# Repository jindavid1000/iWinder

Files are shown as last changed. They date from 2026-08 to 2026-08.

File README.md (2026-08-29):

<div align="center">

### 3D 打印智能绕线器 · 手机 APP 无线控制

ESP32 + 舵机丝杆排线 + 直流电机收线，把散装线材整齐绕到任何料盘上。

**不只绕耗材——电线、绳线、织带，通通能绕。**





</div>

---
QQ 交流群：1103884695

## ✨ 项目亮点

- 📱 **手机 APP 无线控制** — WiFi 连接，实时监控转速/长度/排线位置，不用守在机器旁边
- 🧵 **自适应排线** — 排线速度根据料盘实际转速自动同步，每圈移动一个线径，紧密排列无间隙
- 🎛️ **全程可调** — 线径、料盘尺寸、速度、排线范围全部 APP 里改，支持保存 10 组预设方案
- 🔧 **几乎兼容所有料盘** — 拓竹、eSUN、随便什么牌子，尺寸不合适随时调参数
- 💰 **成本低** — 全套约 ¥56+（不含打印件），手摇版最省
- 🔓 **部分开源** — APP 源码、固件外围源码、硬件与 3D 模型开放（非商业）；核心排线算法闭源，固件以二进制发布

## 🎯 能绕什么？

| 线材类型 | 说明 |
|---|---|
| 3D 打印耗材（PLA/PETG/TPU...） | 1.75mm / 2.85mm / 3mm，默认拓竹 1kg 料盘 |
| 电线 / 线束 | 绕到线盘上，排线整齐不乱 |
| 钓鱼线 / 细绳 | 换个料盘就能绕 |
| 织带 / 扁平带材 | 调整排线间距即可 |

> 只要料盘装得上去、参数调得好，什么都能绕。

---

## 📸 效果展示

### 整机外观

<div align="center">



</div>

### APP 界面

<div align="center">
<table>
<tr>
<td align="center"><b>设备连接</b></td>
<td align="center"><b>控制面板</b></td>
</tr>
<tr>
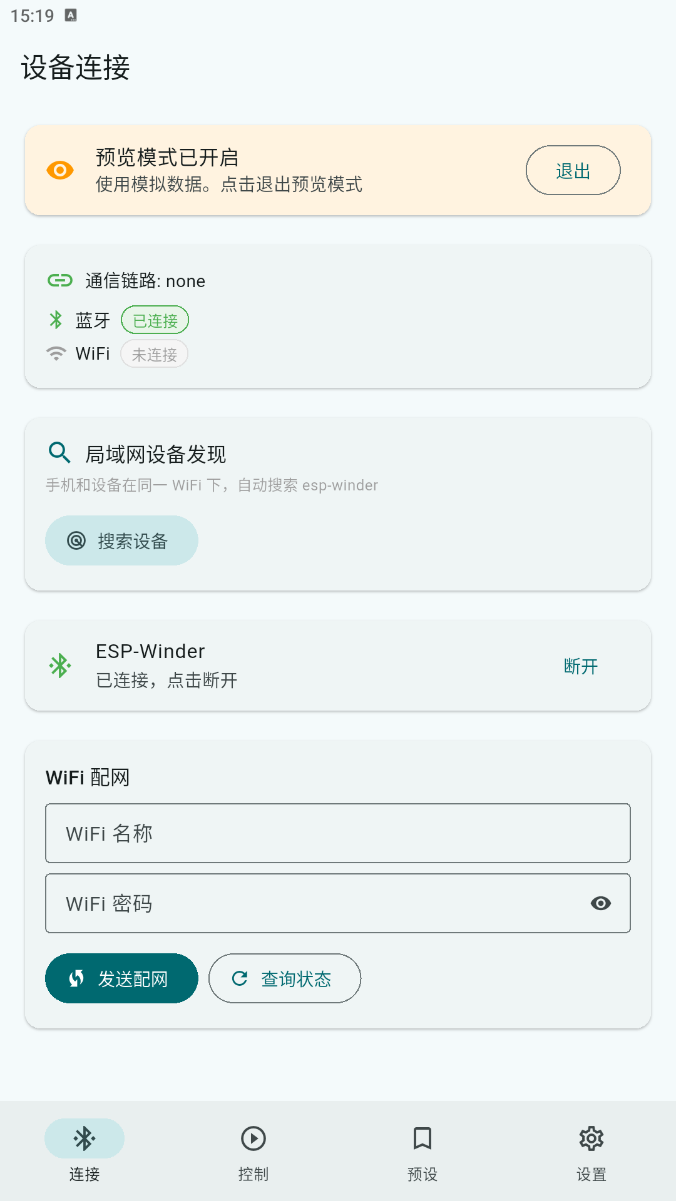
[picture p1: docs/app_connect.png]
<td align="center"><br><sub>WiFi 配网 / 局域网搜索 / 直连 IP</sub></td>
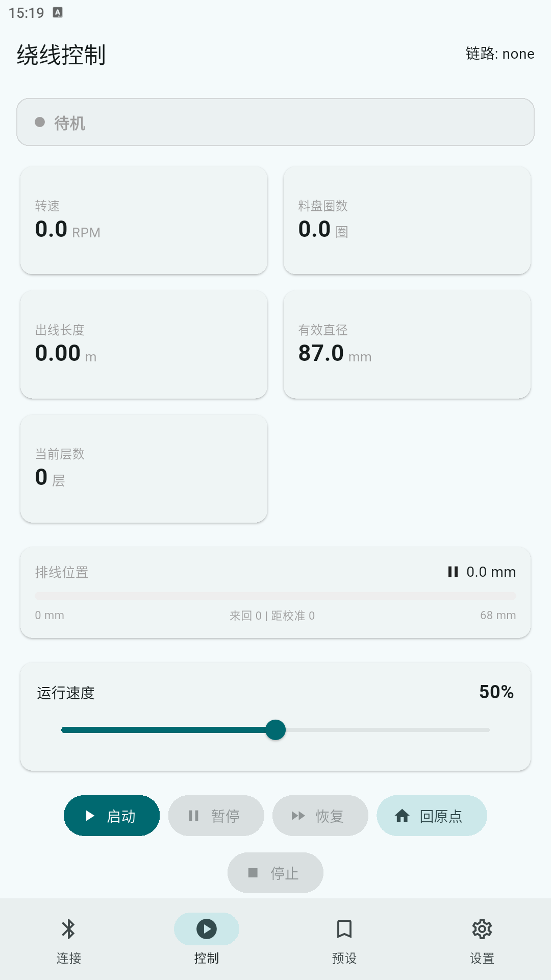
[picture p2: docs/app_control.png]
<td align="center"><br><sub>启停控制 / 实时调速 / 运行监控</sub></td>
</tr>
</table>
</div>

<div align="center">
<table>
<tr>
<td align="center"><b>参数预设</b></td>
<td align="center"><b>设置页面</b></td>
</tr>
<tr>
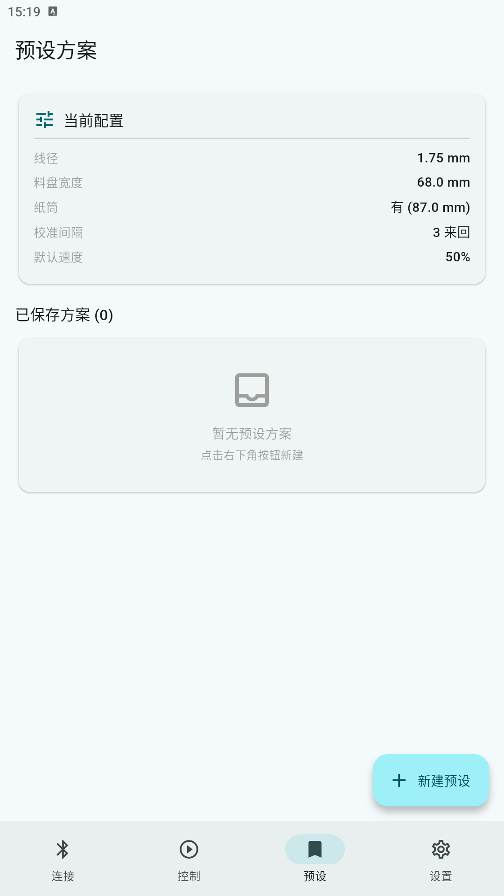
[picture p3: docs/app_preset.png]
<td align="center"><br><sub>料盘参数管理 / 一键切换方案</sub></td>
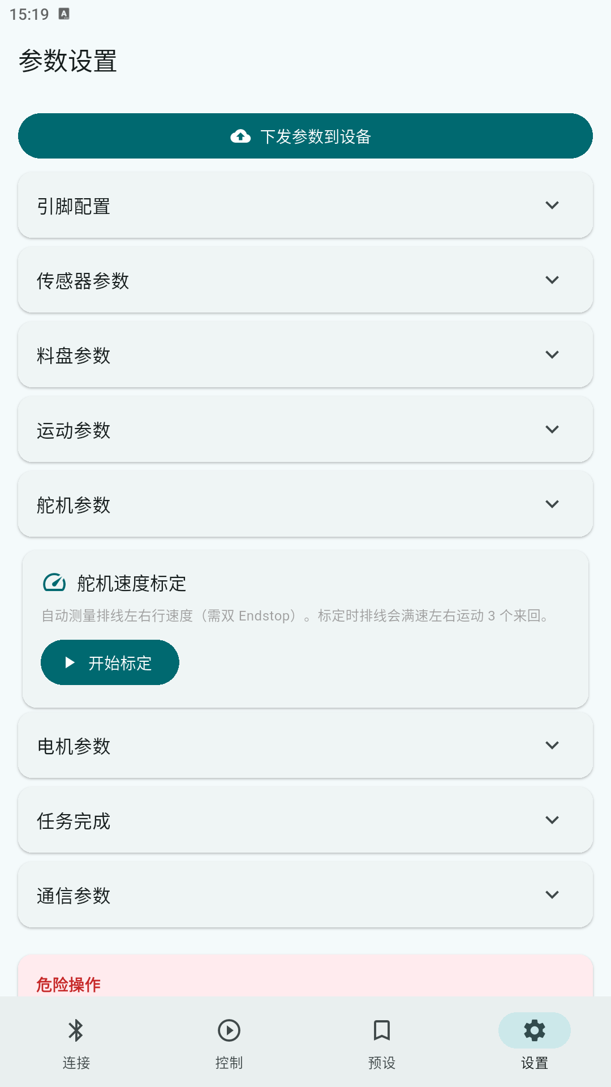
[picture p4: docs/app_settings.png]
<td align="center"><br><sub>引脚/传感器/舵机/电机全部可调</sub></td>
</tr>
</table>
</div>

### 运行演示

> 🎬 运行 GIF 待补充（绕线过程 + APP 实时数据）

---

## 🏗️ 组装

> 详细组装视频可参考原作者 [废改实验室](https://makerworld.com.cn/zh/models/2379707-san-liao-rao-xian-qi-shou-yao-dian-dong) 的教程（电机部分）。
> 图文安装说明见 [`docs/安装说明.pdf`](docs/安装说明.pdf)。

### 版本选择

本项目提供三个版本，核心排线机构相同，区别在收线驱动方式：

| 版本 | 成本（不含打印件） | 适合人群 | 特点 |
|---|---|---|---|
| **手摇/电钻** | ~¥56 | 预算有限 | 手摇或电钻驱动，最经济 |
| **单电机** | ~¥80 | 推荐首选 | 电机自动收线，解放双手 |
| **双电机** | ~¥98 | 追求扭矩 | 双电机驱动，更强力 |

> 详细 BOM 见 [`BOM/`](BOM/) 目录（含拼多多链接和价格）。

### 硬件清单

| 部件 | 规格 | 说明 |
|---|---|---|
| 主控板 | ESP32-DevKitC（普通版） | |
| 收线盘电机 | 直流减速电机 6V 40RPM | 单向收线（单/双电机版） |
| 电机驱动（二选一） | ① IRLB8721 MOS + 150Ω/10kΩ 电阻 + 1N5822（PWM 调速）② L298N 模块（开关，不调速） | ①不可用 IRF520（栅极需 10V）；②接线简单：ENA 插跳线、IN1=GPIO4、IN2=GND |
| 排线编码器（可选，强烈推荐） | AS5600 磁编码器模块 + Φ6 径向磁铁 | 直测丝杆，闭环位置精度 ±0.1mm 级 |
| 排线舵机 | MG946R 360° 连续旋转（首选）/ 鑫辉 18KG（备选） | 驱动丝杆排线 |
| 丝杆 | T8 四头丝杆 + 螺母（导程 22mm） | |
| 霍尔传感器 | KY-003（A3144）× 1 | 料盘计圈 |
| 磁铁 | N35 Φ6×2mm × 8 | 贴在料盘上配合霍尔 |
| 限位开关 | 摆杆式 Endstop × 2 | 左原点 + 右限位 |
| 轴承 | 608ZZ × 8 | |
| 电源 | 多路降压模块（3.3V/5V/12V） | 鹿小班 DCP3512 或等效 |

<details>
<summary>📌 舵机说明（点击展开）</summary>

- **首选：MG946R 360° 连续旋转舵机**（泰尔科技，约 ¥12.2）
  - 需额外打印「模型/配置/mg946 改双轴.3mf」改装件
  - 参考项目：[MG996R 双轴舵机适配器](https://makerworld.com.cn/zh/models/538013) by LaphaeL
- **备选：鑫辉 18KG 360° 连续旋转舵机**（约 ¥31）
  - 自带金属舵盘，无需改装件
  - 支持 7.4V，扭矩更大
- ⚠️ 两个都是 **360° 连续旋转舵机**，不是普通 180° 位置舵机

</details>

### 接线

**ESP32 信号线**

| ESP32 引脚 | 连接 |
|---|---|
| GPIO 4 | 电机驱动：MOS 方案接栅极（经 150Ω），L298N 方案接 IN1 |
| GPIO 5 | 舵机 PWM 信号线 |
| GPIO 14 | Endstop 左（绕线起始侧）信号 |
| GPIO 32 | Endstop 右（**原点侧**，上电寻原点时小车停靠的一侧）信号 |
| GPIO 27 | 霍尔传感器信号 |
| GPIO 21 | AS5600 编码器 SDA（可选） |
| GPIO 22 | AS5600 编码器 SCL（可选） |
| GPIO 2 | 板载 LED（状态指示，无需外接） |

**供电**

| 电源模块输出 | 连接 |
|---|---|
| 3.3V | ESP32 3V3 脚、霍尔传感器 VCC、Endstop 信号公共端、AS5600 VCC |
| 5V | 舵机 VCC |
| 12V | 电机供电：MOS 方案——电机正极，电机两端并联 1N5822 续流二极管（负极朝 12V 端），电机负极接 IRLB8721 漏极（D），源极（S）接 GND，栅极经 150Ω 接 GPIO4、10kΩ 下拉到 GND；L298N 方案——接模块 +12V 输入 |
| GND | 所有模块共地 |

> ⚠️ ESP32 的 GND 必须与电机/舵机电源的 GND **共地**，否则 PWM 信号不稳定。
> ⚠️ **电机 PWM 线（GPIO4）不要与舵机信号线（GPIO5）并排/捆扎走线**——PWM 开关噪声
> 会耦合进舵机信号，导致排线在"停止"状态下仍缓慢漂移。固件已将电机 PWM 提到 20kHz
> 缓解，但布线时仍应分开；更稳妥可在舵机信号线上加 RC 滤波（串 1kΩ + 对地 100nF）。
> ⚠️ **AS5600 磁铁装丝杆轴端**，轴向对准芯片中心、间隙 0.5~2mm、尽量同心——
> 磁铁偏心是这类编码器最大的误差源。装好后先跑 `test_encoder` 验证无漂移。
> ⚠️ **Endstop 安装**：以"刚刚触发"状态为基准（摆杆压过咔哒点再多 0.3~0.5mm 固定），
> 剩余超程作为寻原位停止冲量的缓冲。两个限位触发点之间的真实距离用 `test_encoder`
> 测出（小结行会打印），填入「限位间距」参数——限位绝对装在哪不重要，重复性才重要。
> 引脚全部可在 `esp32/include/config.h` 中修改，也可通过 APP 运行时调整。
> ⚠️ **限位左右别接反**：以功能区分——**右限位是原点侧**（上电后小车寻原点时向右顶到的那个），
> 左限位是绕线起始侧。接反的典型表现：上电寻原点显示「右原点已确认」，随后定位立刻报
> `sensor_error - 定位顶左限位且偏差>3mm`，且串口 `[POS]` 行末尾**同时**出现 `[左限位] [右限位]`。
> 修法：对调 GPIO 14 / GPIO 32 两根信号线，或在 APP 设置页把两个限位引脚值互换。
> 接好后可用 `pio run -e test_endstop -t upload` 分别按压两个摆杆验证左右一一对应。

### 3D 打印

`模型/` 目录下提供所有打印件。推荐使用 Bambu Studio 切片，**PETG**（所有模型均在 PETG 下测试通过），PLA 也可以。

---

## 🚀 使用指南

### 第一步：烧录固件

固件以编译好的二进制发布（核心算法不开源），最新版本在本仓库 [`firmware/`](firmware/) 目录
（[Releases](../../releases) 页面有历史版本）。

**网页烧录（推荐，无需装任何软件）**：

1. USB 连接 ESP32 到电脑
2. Chrome/Edge 打开 **[esptool.spacehuhn.com](https://esptool.spacehuhn.com/)** → Connect 选串口
3. 第一个槽地址改成 **0x0**，选 `iWinder_full.bin`（合并镜像），其余槽留空 → Flash
4. 完成 → 重新上电，ESP32 启动热点 **ESP-Winder**

详细步骤（含增量升级方法）见 [`firmware/README.md`](firmware/README.md)。

**命令行烧录**（合并镜像一步完成）：

```bash
pip install esptool
esptool.py --chip esp32 --port 串口号 write_flash 0x0 iWinder_full.bin
```

烧录完成后设备自动启动热点 **ESP-Winder**（串口 115200 可看启动日志）。

> 💡 可单独测试硬件模块：`pio run -e test_motor -t upload`（可选：`test_led`、`test_servo`、`test_hall`、`test_endstop`、`test_encoder`、`test_wifi`）
>
> `test_encoder` 会驱动排线满速来回扫描（限位自动换向），打印编码器角度/圈数/位置/速度、
> 磁场质量诊断和匀速偏心检测，并在每趟小结限位间圈数 × 导程（⚠️ 含停稳回弹约 5mm，
> 精确限位间距以定位日志的右锚定坐标 − 左触发坐标为准）。

### 第二步：安装 APP

**最简方式（推荐）**：无需安装任何东西——烧录固件后，手机/电脑浏览器直接访问设备：

- 热点模式：连上 WiFi **ESP-Winder** 后打开 `http://192.168.4.1`
- 家庭 WiFi 模式：iOS/macOS 浏览器直接打开 `http://iwinder.local`（mDNS 自动解析）；
  其他设备可从串口日志或 App「搜索设备」获取 IP 后访问

Web 界面支持控制（启停/调速/手动模式）、实时状态、参数修改和舵机标定，iOS/安卓/电脑通用。
只要设备连入了局域网（家庭 WiFi）或开着热点（ESP-Winder），同一网络内的任何浏览器
都可以访问，无需安装、无需账号；可多端同时在线，与安卓 App 互不干扰。

> ⚠️ 家庭 WiFi 模式要求访问设备与 ESP32 连**同一个路由器**，且路由器关闭了
> 「AP 隔离 / 客户端隔离 / 访客网络隔离」——开着隔离的表现是能解析出
> `iwinder.local` 但页面打不开。部分路由器对 IoT 设备默认隔离，需要在管理界面放行。
>
> 💡 设备端负载：Web/APP 在线时 CPU 占用 <15%，控制循环为闭环设计（编码器实测位置 +
> 硬件 PWM），偶发的网络处理延迟（毫秒级）不影响绕线精度，多端同时连接也无需担心。

也可以使用功能更完整的安卓 APP：

从本仓库 [`firmware/`](firmware/) 目录下载最新 `app-release.apk`，传到手机安装
（[Releases](../../releases) 有历史版本）。

<details>
<summary>或自行编译（需要 Flutter 环境）</summary>

```bash
cd app
flutter pub get
flutter build apk --release
# 产物：build/app/outputs/flutter-apk/app-release.apk
```

</details>

### 第三步：连接设备

ESP32 上电后会启动 **WiFi 热点（ESP-Winder）**。

1. 手机 WiFi 设置里连接热点 **ESP-Winder**
2. 打开 APP → IP 填 `192.168.4.1`，端口 `8080` → 连接
3. 在「WiFi 配网」输入家庭 WiFi 密码 → 发送配网
4. 手机切回家庭 WiFi，以后用「搜索设备」自动发现连接

### 第四步：开始绕线

1. **选驱动模式**：设置页「驱动模式」→ 电动（电机驱动）或 手动（手摇驱动，电机不输出）。
   用 L298N 驱动板的话把「电机驱动电路」切到 L298N——此模式无调速，电动模式启动即全速
2. **选预设**：默认拓竹 1kg，可自定义线径/料盘尺寸
3. **标定**（设置页）：
   - 装了 AS5600：切「AS5600 编码器闭环」（齿比填 1.0），点「舵机速度标定」——
     自动测量满速/步进速度、编码器每圈位移并写入 NVS
   - 未装编码器：用默认「舵机开环估算」，必须先跑「舵机速度标定」才能启动
4. **启动**：电动模式拖速度滑块调速启动；手动模式直接启动后手摇，排线自动跟随转速
5. **运行监控**：APP 实时显示转速、圈数、长度、排线位置
6. **停止**：点「停止」，排线自动回原点归位

**手动模式行为**：手摇越快排线越快，停手约 1 秒排线暂停；停转约 2 秒（且来回数达标）
自动触发一次限位校准并回到原位置继续。电动模式带缠料保护（电机运转但料盘停转 4 秒
自动**暂停**并提示，清理后点「恢复」继续绕线，无需重新定位）。

---

## ⚙️ 参数调校

首次使用在 APP 设置页面配置/标定：

| 参数 | 说明 |
|---|---|
| 驱动模式 | 电动（电机）/ 手动（手摇），行为差异见上 |
| 电机驱动电路 | MOS 管调速（PWM，支持软启动/调速滑块）/ L298N 开关（ENA 插跳线全速，只能启停不能调速，方向由接线决定） |
| 位置反馈 | 舵机开环估算 / AS5600 编码器闭环（装编码器后强烈建议开启；绕线中为连续旋转速度自适应控制，平滑跟随） |
| 排线速度标定 | 自动测量满速 3 个来回 + 步进速度 1 个来回；编码器模式下还会标定每圈位移 |
| 限位间距 | 左右限位**触发点**之间的真实距离（默认 62mm）。⚠️ 用 `test_encoder` 测量时注意「右停稳→左触发」含柔性回弹（偏大约 5mm），最准的方法是：绕线/定位日志中右锚定坐标 − 左触发坐标 |
| 霍尔去抖 | 默认 25000us（滤除电机 PWM 耦合噪声），真实转速超 300RPM 才需调小 |
| 料盘参数 | 外径、宽度（拓竹料盘宽 60mm，默认已填）、芯轴直径（有/无纸筒可切换）——只影响长度/层数计算 |
| 绕线范围 | **右基准模型**：右终止位置（默认 62mm，由机器安装决定）+ 料盘宽度 → 左起始自动推导（= 右终止 − 宽度）。换盘只改宽度一个数字；料盘左右都不固定的特殊安装可勾「左起始手动指定」。绕线宽度 = 右终止 − 左起始，界面实时校验与料盘宽度的一致性 |
| 校准间隔 | 电动: 每几个来回校准一次；手动: 停转触发校准前至少需要的来回数 |
| 缠料保护 | 电动模式电机运转但料盘 0 转速持续 4 秒自动**暂停**（保留进度），清理后点「恢复」继续 |

所有参数支持保存为预设方案（最多 10 组），一键切换。ESP32 断电后参数保存在 NVS 中不会丢失。
⚠️ 固件升级若改动 DeviceConfig 结构体，首次启动会重置参数（WiFi 凭据保留），需重新配置下发。

---

## 📁 项目结构

```
├── app/            # Flutter 手机 APP（Android）源码
├── esp32/          # ESP32 固件外围源码（核心算法闭源，仅供参考）
├── firmware/       # 编译好的固件二进制与 APP 安装包（含烧录说明）
├── 模型/           # 3D 打印模型文件（.3mf，源文件为 Fusion 360 格式）
├── BOM/            # 硬件采购清单（三个版本）
└── docs/           # 安装说明等文档
```

---

## 🙏 鸣谢

- [废改实验室](https://makerworld.com.cn/zh/models/2379707-san-liao-rao-xian-qi-shou-yao-dian-dong) — 原始散料绕线器设计
- [LaphaeL](https://makerworld.com.cn/zh/models/538013) — MG996R 双轴舵机适配器

## 可选配件

- [耗材旋转支架](https://makerworld.com.cn/zh/models/1705115-hao-cai-xuan-zhuan-zhi-jia) — 放散料用，省料

---

## 🔑 申请授权

固件内置设备授权：**许可证免费申请，一人一机**。

**方式一：一键申请（推荐，全自动）**

设备连上 WiFi 后，在 Web 界面或 APP 的「授权」页填个昵称，点**「一键申请」**
即可自动获取并填入许可证（自动批准），点**激活**就能用了。也可以到
[授权网站](https://tt.jyking.dpdns.org:1000/) 网页申请：填设备 ID 提交，
把返回的许可证粘贴到设备「授权」页激活。

**方式二：QQ 群**

加入 QQ 群 **1103884695** 找作者，发设备 ID（授权页可查）即可。

> 未授权时可以正常连接、调参、回原点、标定，只是无法启动绕线任务。
> 许可证默认有效期一年，到期在原页面重新申请即可（免费，自动批准）。
> 商业授权（整机/套件销售、衍生产品）通过 QQ 群联系。

---

## License

本项目采用分层许可（详见 [LICENSE](LICENSE)）：

| 内容 | 许可 |
|---|---|
| 固件二进制 | 专有许可，免费激活使用，禁止逆向与商用 |
| APP / 固件外围源码 | PolyForm Noncommercial 1.0.0 |
| 3D 模型 / 硬件设计 / 文档 | CC BY-NC 4.0 |

3D 打印结构件为经原作者授权的二次创作设计，原作者不允许商用，本项目已获原作者许可并合作开发。

---

<div align="center">

制作不易，如果这个项目对你有帮助，欢迎 ⭐ Star 支持一下（当然如果愿意助力我买个 fusion 的话我也是不介意的😄）！
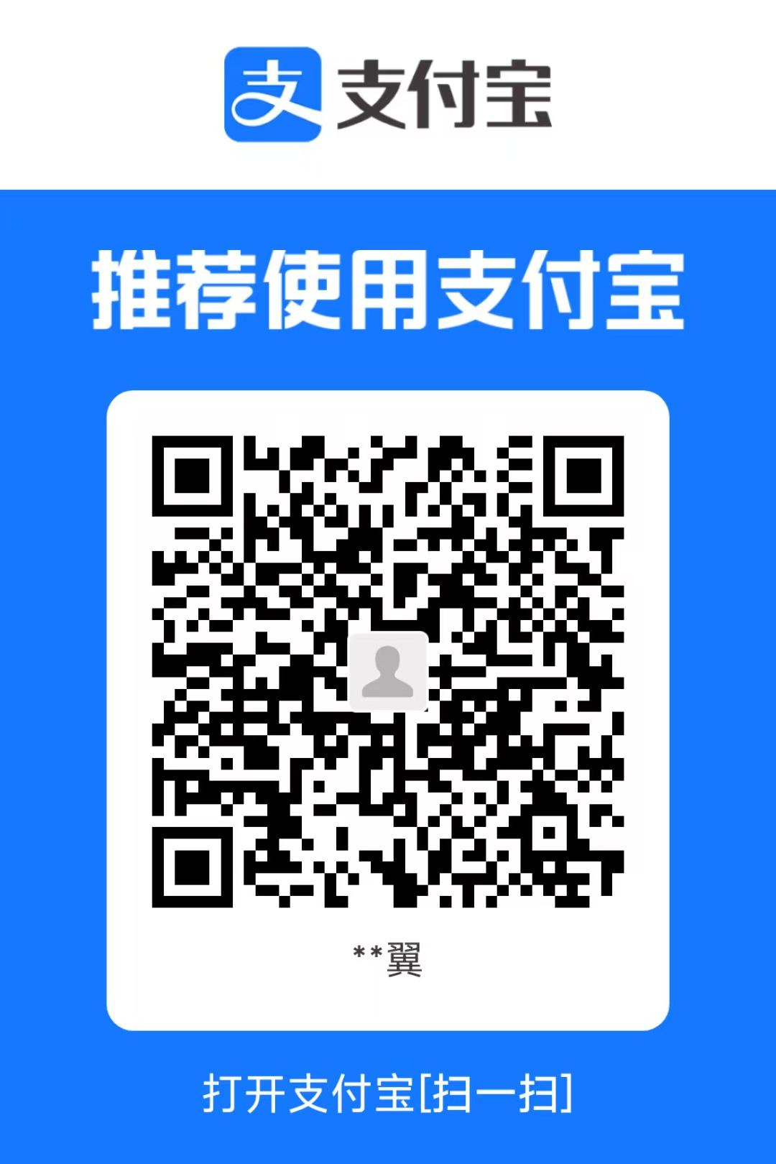
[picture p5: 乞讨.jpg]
截图


</div>

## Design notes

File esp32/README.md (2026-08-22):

# esp32/（固件外围源码，仅供参考）

本目录只包含固件的**外围部分**：通信、Web 界面、参数存储、传感器/电机/
舵机驱动等，供学习与二次开发参考。

**核心算法（自适应排线同步、绕线控制状态机、舵机标定）与设备授权模块不开源**，
仅以编译好的固件形式在 [Releases](../../releases) 发布。

因此本目录**无法独立编译成可用固件**。如需使用固件，请直接下载 Releases 中的
`.bin` 烧录；如需商业授权或算法合作，见项目 README。

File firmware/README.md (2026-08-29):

# 最新固件与 APP（v0.2.10）

| 文件 | 用途 |
|---|---|
| `iWinder_full.bin` | **推荐**。完整镜像（bootloader+分区表+固件），一条命令烧录 |
| `firmware.bin` | 仅应用固件，刷过旧版的设备更新用（`write_flash 0x10000`） |
| `app-release.apk` | 安卓 APP |

完整镜像烧录：

```bash
pip install esptool
esptool.py --chip esp32 --port 串口号 write_flash 0x0 iWinder_full.bin
```

> 这里只保留最新版本；历史版本见 [Releases](../releases)。
> 已联网设备可直接在 Web 界面「授权」页或 APP 在线升级（OTA），无需连电脑。

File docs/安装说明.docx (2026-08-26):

安装说明

一、零件展示

图示

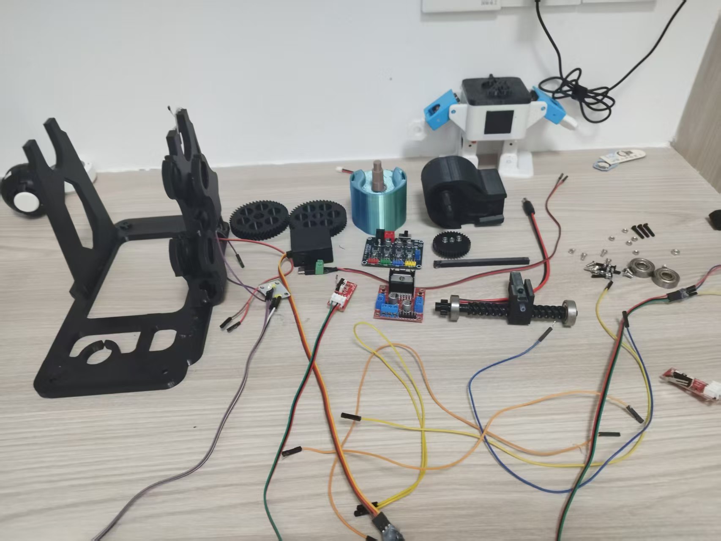
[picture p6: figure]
微信图片_20260826160315_27_6

二、丝杆和滑块安装

所需零件

特氟龙管一小节，丝杆、丝杆固定、螺母、从动小齿轮、as5600磁铁放置（打印件的名字），608zz轴承两个，m3*6螺母3个（滑块上)，m3*18螺丝一个，m2*18螺丝两个，as5600附赠的4*2直径充磁磁铁，，，，，（适量胶水）

操作说明

滑块：把特氟龙管插进去，然后用m3*6螺丝上紧，把整个滑块放进丝杆里，

丝杆：把两个轴承放到两端，然后用丝杆固定放在丝杆右边（伸出来轴短一点的那一边），用m3*18螺丝上紧（可能要打胶），左端按照顺序装配：先放从动小齿轮，再在上面放as5600磁铁放置，把孔位对齐，用m2*18螺丝上紧（上到底），然后把磁铁卡到as5600磁铁放置的正中心（可以让磁铁先吸到一块平的铁板上，然后用力的按下去）

图示

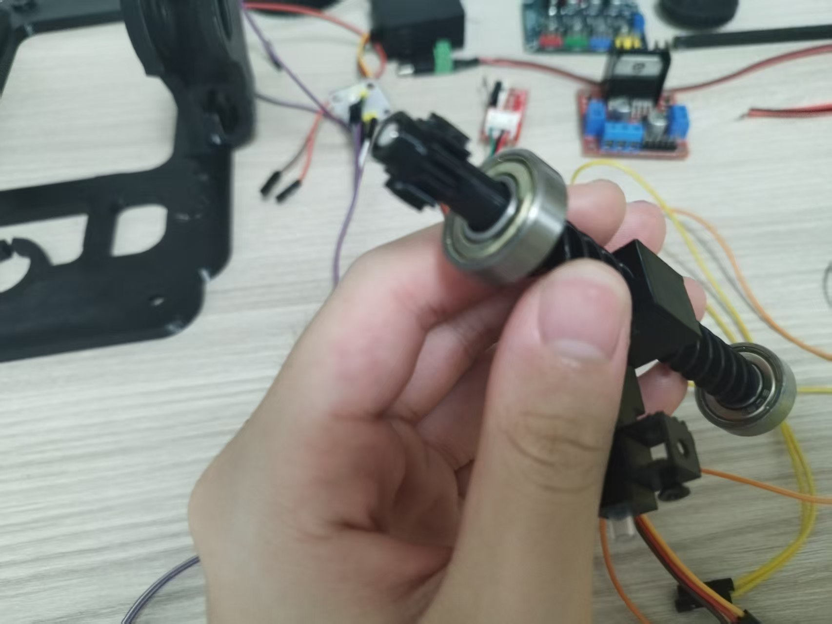
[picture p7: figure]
微信图片_20260826160314_25_6
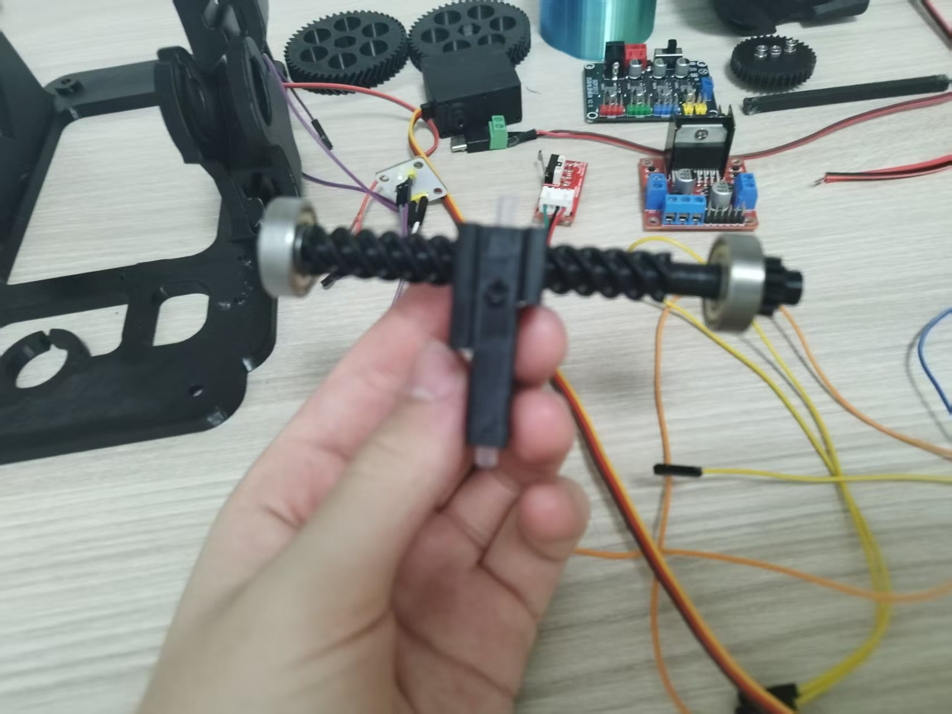
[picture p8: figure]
微信图片_20260826160314_26_6
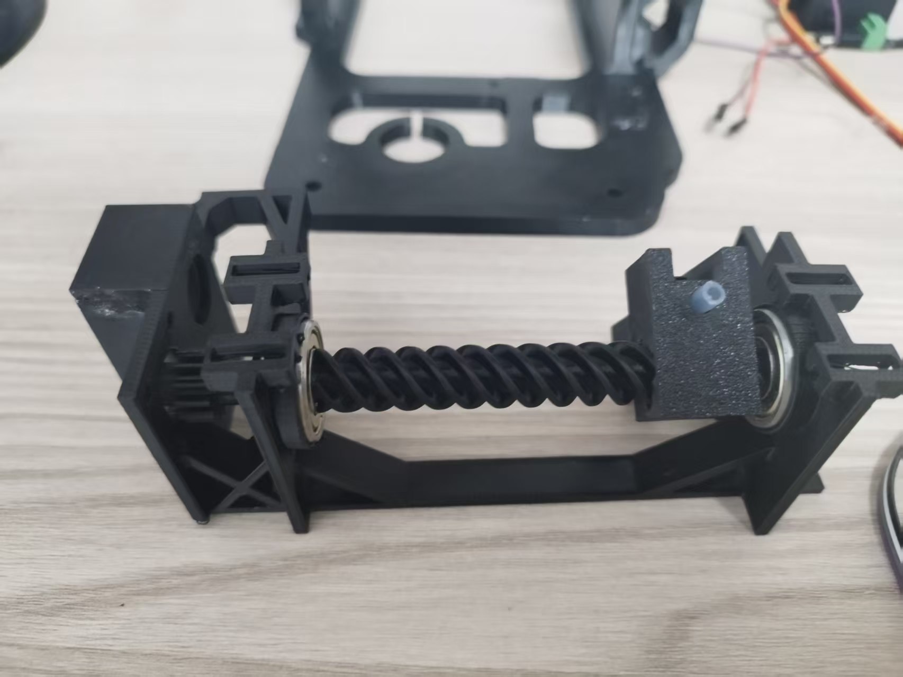
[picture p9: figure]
微信图片_20260826160311_22_6
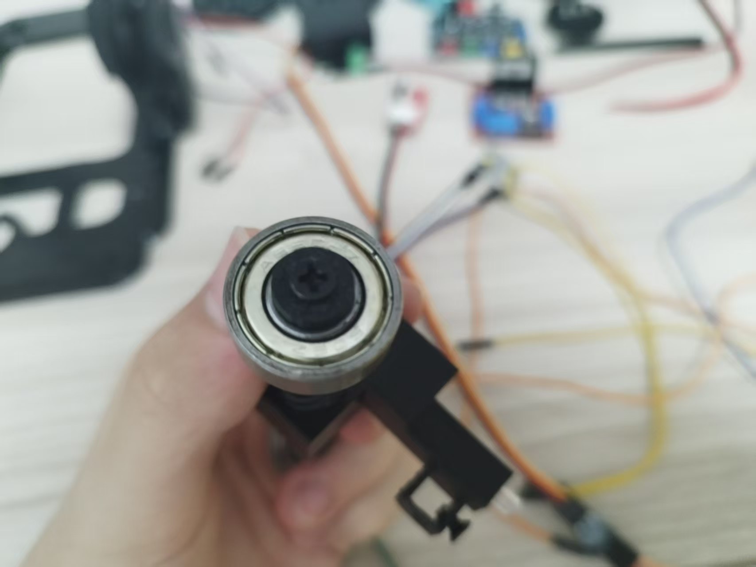
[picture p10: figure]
微信图片_20260826160312_23_6

三、舵机、舵盘和大齿轮安装

所需零件

金属的25T舵盘，舵机（用mg946r的话需要改），m3*10螺丝3个（没试过怎样，我看着应该是9mm的最完美，用12mm的话也可以，但是需自备螺母），主动大齿轮（打印件名字）

操作说明

把舵盘和大齿轮连接，中间一个连接舵机轴的螺丝先别上太紧，然后先把舵盘放进去，对准孔位，把舵机插进来，上紧螺丝

图示

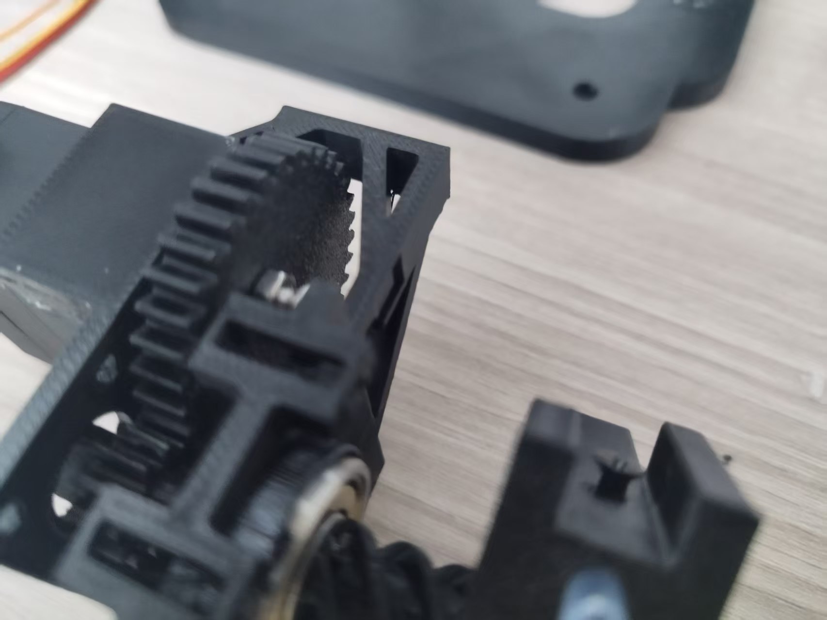
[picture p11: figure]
微信图片_20260826160308_19_6
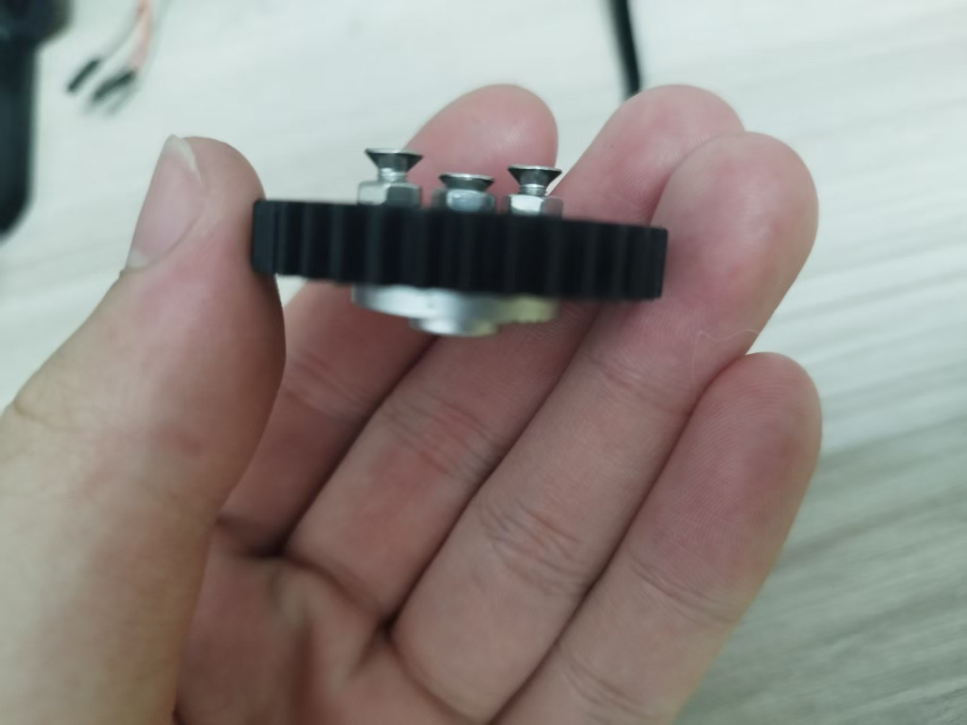
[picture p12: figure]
微信图片_20260826160310_21_6

四、固定杆安装

所需零件

平行于丝杆的定位小杆（打印件名字，好奇葩）

操作说明

对准孔位，用热熔胶固定即可

图示

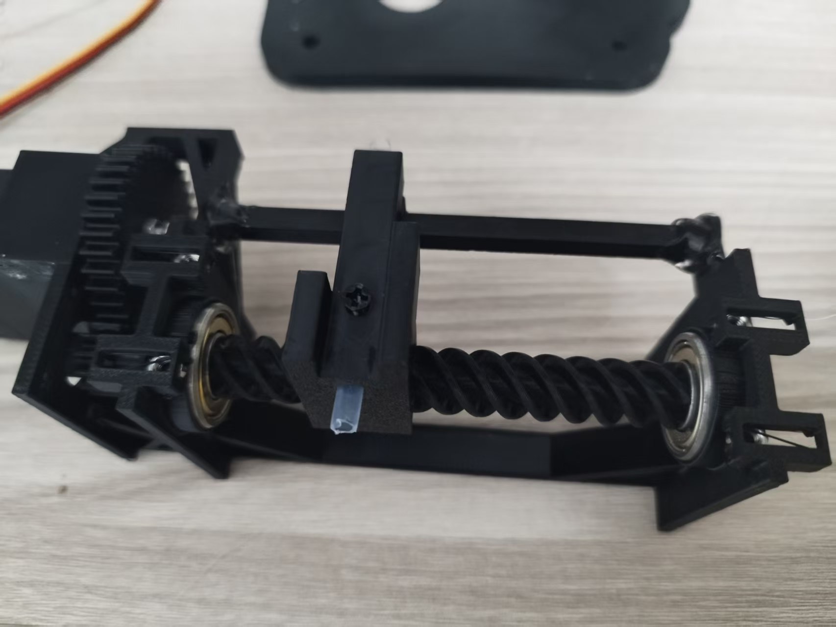
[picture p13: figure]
微信图片_20260826160306_16_6

五、endstop 安装

所需零件

两个endstop，4个m3螺母，4个m3*8螺丝，

操作说明

把核心框架翻到反面，用在四个框中塞入4个螺母，推到底，把endstop放到上面，用螺丝固定，可稍微调整

图示

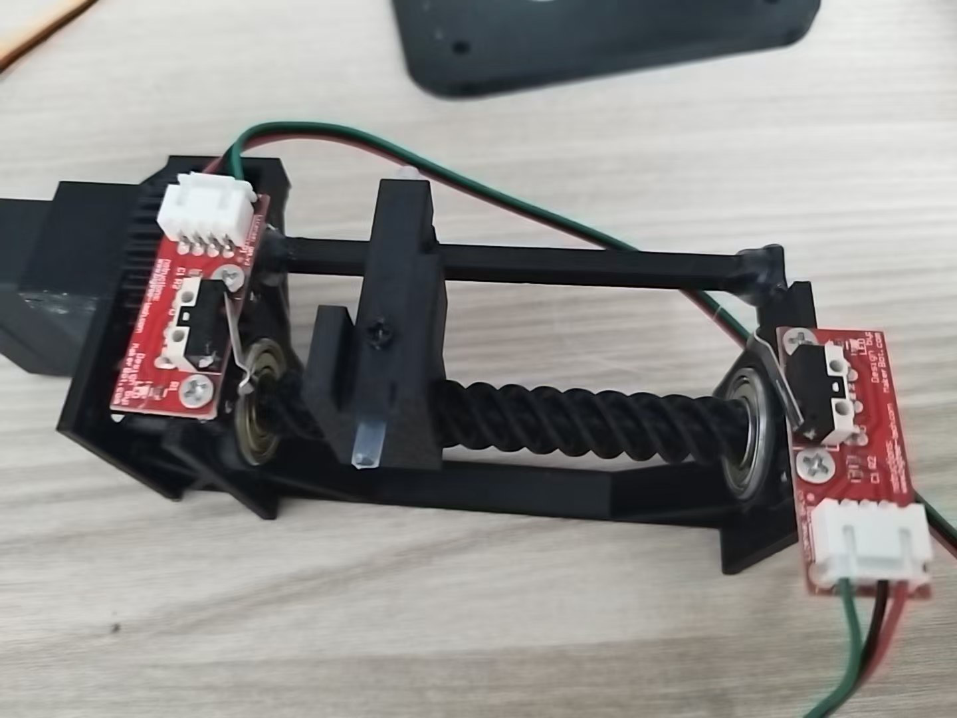
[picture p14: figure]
微信图片_20260826160305_15_6

六、as5600 编码器安装

所需零件

as5600编码器，m3*8螺丝4个，m3螺母4个

操作说明

把螺丝放进as5600的孔位，然后稍微上紧螺母，让螺丝的头和螺母齐平，对准核心框架侧边的孔位，上紧（注意方向，as5600一定要保证3个针脚的朝上）

图示

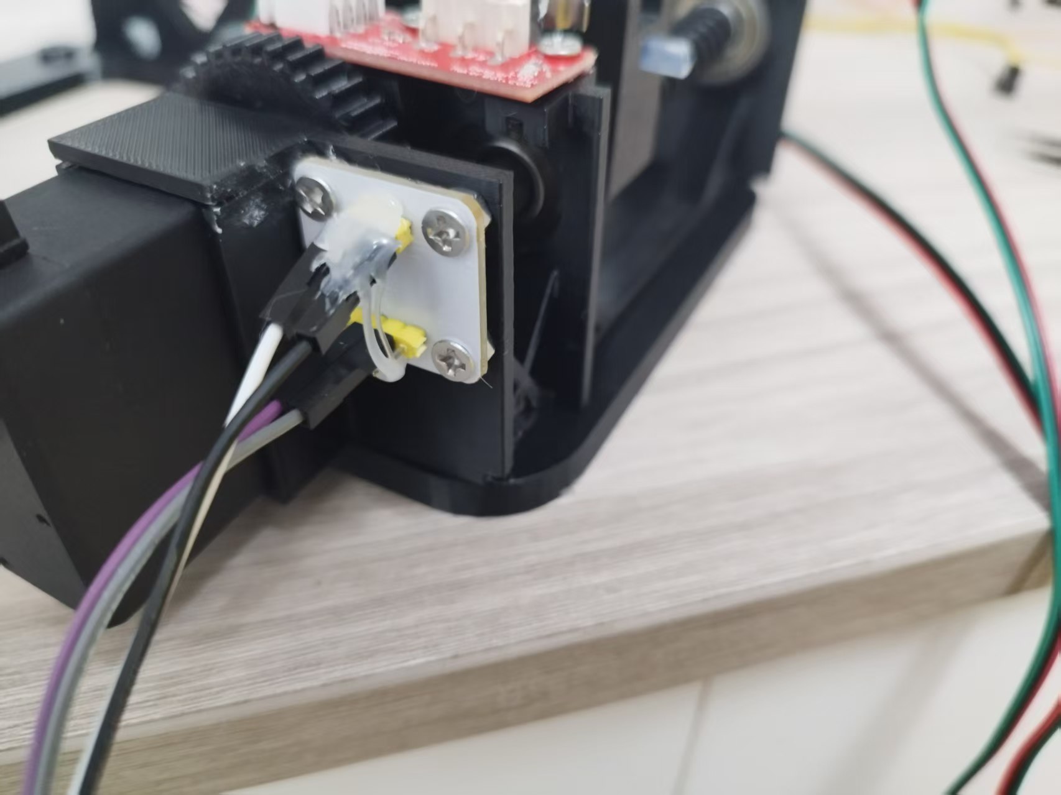
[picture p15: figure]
微信图片_20260826160302_12_6

七、总装配

所需零件

m3*8螺丝6个，m3螺母6个，（电源的孔位是给鹿小班开的，如果买的是bom上的直接用热熔胶，那么螺丝螺母只要3个）ky003霍尔模块，mos管（需要电阻和二极管，可以搞一个小面包板装好）或l298n

操作说明

把前面做好的核心模块固定到主体上（左边放螺母的地方需要用电烙铁加热螺母放进去，），然后用热熔胶粘上霍尔，调整好位置，电源如果用的是bom里的就也粘在侧面就行，其它有螺丝孔的就压入螺母，放上模块，用螺丝上紧

图示

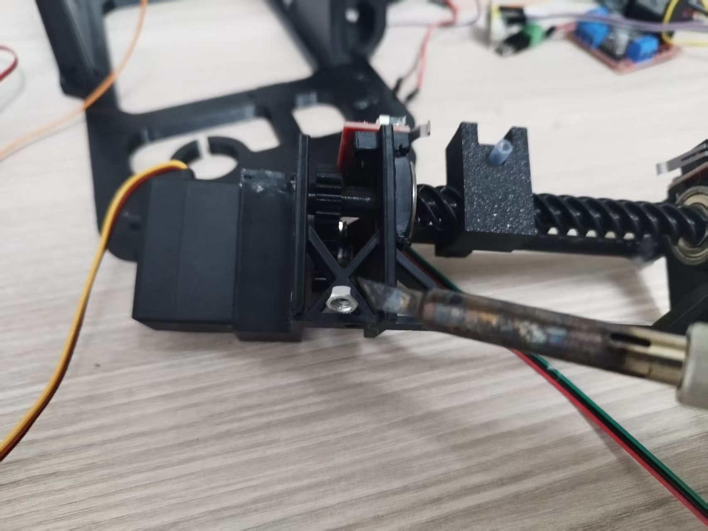
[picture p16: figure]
微信图片_20260826160304_14_6

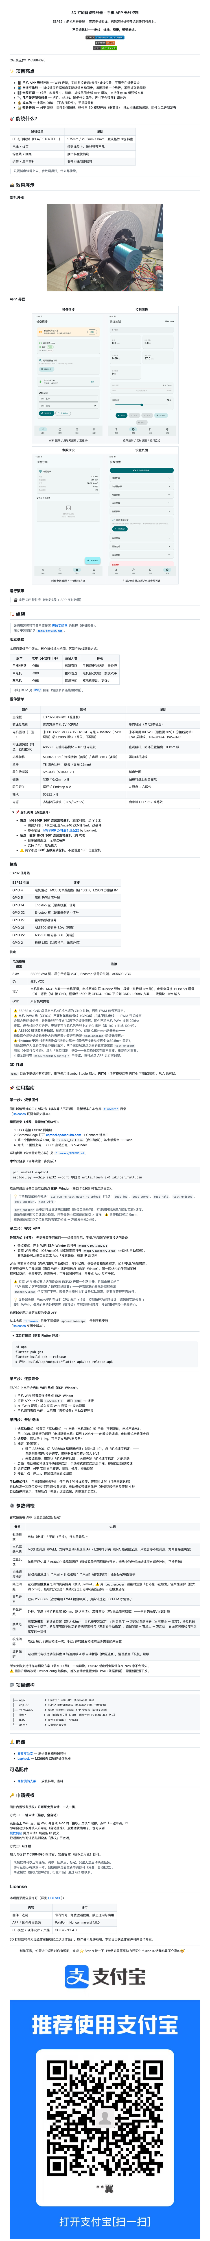
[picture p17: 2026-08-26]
readme.png

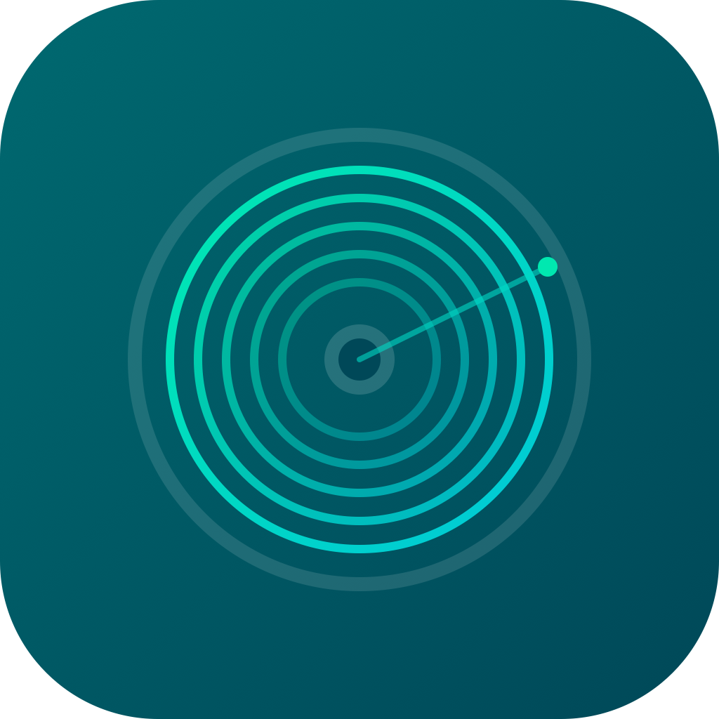
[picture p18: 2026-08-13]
app/assets/ic_launcher.svg.png

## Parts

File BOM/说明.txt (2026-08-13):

所有零件都可以在拼多多购买（价格全部为券前价），用什么版本看自己的需要，核心部分都是一样的，不一样的只有驱动部分，比较推荐手摇版，经济实惠，可以使用电钻等工具加速，单电机就比较省心（需注意接线），电机直接挂在上面，可以解放一只收，双电机具有单电机的有点，并且扭矩更强，但是接线更麻烦，需要注意，如果想做电机但是手残可以到废改3d散料盘料耗材的咸鱼看看，他是原作者

【舵机选择】
首选 MG946R（360°连续旋转版，泰尔科技，约12.2元），需要额外打印「模型/配置/mg946 改双轴.3mf」这个改装件把舵机的外壳改的适配这个项目（如使用此舵机，需另备金属舵盘或者在 makerworld 上找一个 25t 的花键舵盘，推荐 6v，不能更高）。
备选鑫辉科技 18KG 360°连续旋转舵机（买自带金属舵盘的版本或者在 makerworld 上找一个 25t 的花键舵盘，无需改装件，约31元（金属舵盘价）推荐 7.4v）。
注意：两个舵机都是 360° 连续旋转舵机，不是普通的 180° 位置舵机。

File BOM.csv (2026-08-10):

序号 | 名称 | 规格/型号 | 数量 | 单价(元) | 小计(元) | 备注
1 | DC电源插座 | 5.5×2.1圆形母座 配防水帽 5个装 | 1 | 3.24 | 3.24 | 达拉然电子配件
2 | 直流减速电机 | DC6V D型出轴 50转/分 大扭矩 | 1 | 18 | 18
3 | PWM电机调速器 | 1803BK 1.8-12V 2A 带开关 | 1 | 3.08 | 3.08 | 尚芯宇电子科技
5 | 608ZZ轴承 | ABEC-7 10个装 | 1 | 3.1 | 3.1 | AM轴承转动
6 | 机械限位开关 | 3D打印机Endstop RAMPS 1.4 | 2 | 3.4 | 6.8 | 巽风模块
7 | 霍尔磁力传感器 | KY-003 | 1 | 3.04 | 3.04 | 科信科技
8 | 杜邦线 | 20CM 公公+公母+母母 60根套装 | 1 | 6.2 | 6.2 | 莫奇贝电子
9 | DC电源公母头线 | 12V纯铜芯 公头 5条 | 1 | 3.01 | 3.01 | 源德芯电子
10 | ESP32开发板 | CH340C TYPE-C WiFi+蓝牙 | 1 | 18.3 | 18.3 | 深圳昇信
11 | IRF520驱动模块 | MOS管 PWM调节 | 1 | 3.2 | 3.2 | WAVGAT
13 | 数字舵机 | YOUMI 18KG 全金属齿轮 180° | 1 | 31 | 31 | YM优米科技
14 | 可调降压模块 | LM2596 四路 DCP3512 | 1 | 15.73 | 15.73 | 鹿小班
 | 耗材费 | 388.84g（petg hf） |  |  | 7.7768
 | 总计 |  |  |  | 119.7 | 自备螺丝螺母和胶水，M3，M4都需要，M4买短的，*6*8应该都可以，M3长的短的都要，长的*16*18的样子，短的*6*8

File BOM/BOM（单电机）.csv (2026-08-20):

序号 | 名称 | 规格/型号 | 数量 | 单价(元) | 小计(元) | 备注
1 | DC电源插座 | 5.5×2.1圆形母座 配防水帽 5个装 | 1 | 3.24 | 3.24 | 达拉然电子配件
2 | 直流减速电机 | DC6V D型出轴 50转/分 大扭矩 | 1 | 18 | 18
3 | PWM电机调速器 | 1803BK 1.8-12V 2A 带开关 | 1 | 3.08 | 3.08 | 尚芯宇电子科技
5 | 608ZZ轴承 | ABEC-7 10个装 | 1 | 3.1 | 3.1 | AM轴承转动
6 | 机械限位开关 | 3D打印机Endstop RAMPS 1.4 | 2 | 3.4 | 6.8 | 巽风模块
7 | 霍尔磁力传感器 | KY-003 | 1 | 3.04 | 3.04 | 科信科技
8 | 杜邦线 | 20CM 公公+公母+母母 60根套装 | 1 | 6.2 | 6.2 | 莫奇贝电子
9 | DC电源公母头线 | 12V纯铜芯 公头 5条 | 1 | 3.01 | 3.01 | 源德芯电子
10 | ESP32开发板 | CH340C TYPE-C WiFi+蓝牙 | 1 | 18.3 | 18.3 | 深圳昇信
11 | IRLB8721 MOS管(逻辑电平) | 电机PWM驱动(另配150Ω/10kΩ电阻+1N5822续流二极管) | 1 | 1.5 | 1.5 | 淘宝
13 | 数字舵机 | MG946R 360°全金属齿轮 | 1 | 12.2 | 12.2 | 泰尔科技（需打印「模型/配置/mg946 改双轴」改装件）
14 | 电源模块3.3V 5V 12V多路输出 电压转换模块 DC-DC 12V转3.3V 5V（有钱的换鹿小班的四路可调降压模块舵机接7.4v更有力 | LM2596 四路 DCP3512 | 1 | 2.72（15.73） | 2.72（15.73） | 龙芯科技电子（鹿小班）
12 | AS5600磁编码器模块+径向磁铁 | 排线闭环位置反馈(强烈推荐 | 直测丝杆) | 1 | 7.2 | 7.2 | 淘宝
 | 总计 |  |  |  | 80.17 | 自备螺丝螺母和胶水，M3，M4都需要，M4买短的，*6*8应该都可以，M3长的短的都要，长的*12*16的样子，短的*6*8

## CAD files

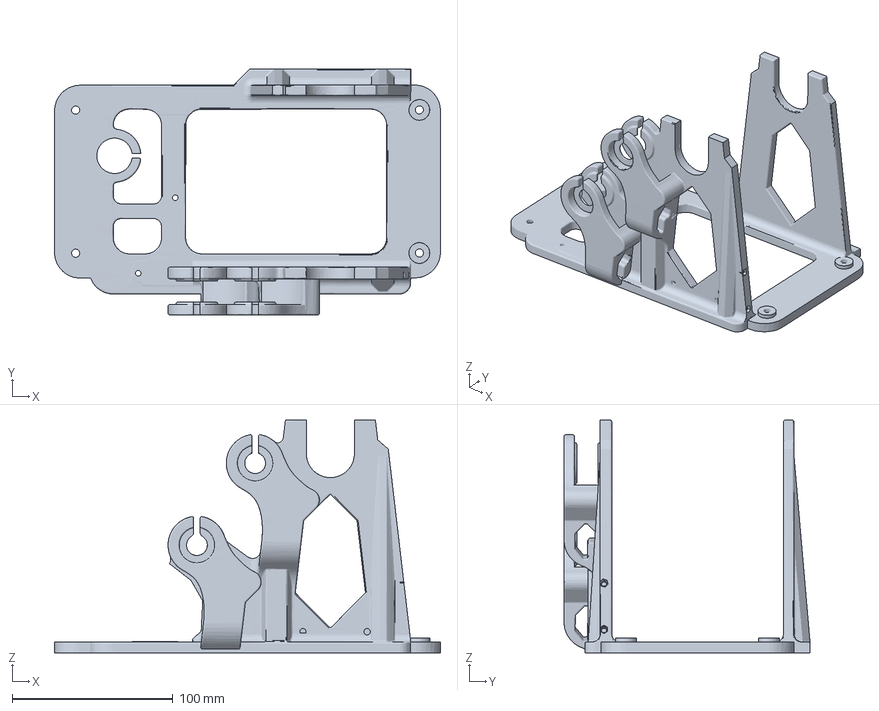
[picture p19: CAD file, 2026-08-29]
模型/主体.3mf
240.1 x 153.0 x 144.8 mm

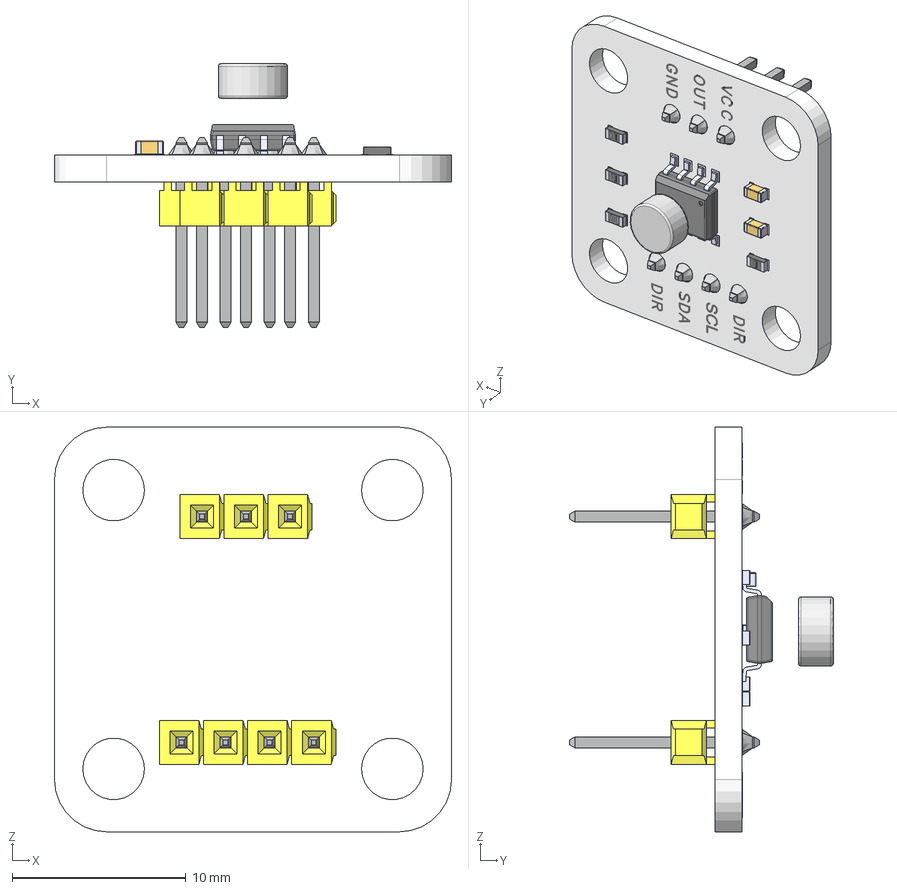
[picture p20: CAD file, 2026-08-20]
模型/源文件/as5600.step
22.9 x 15.2 x 23.3 mm
pin
MAGNET

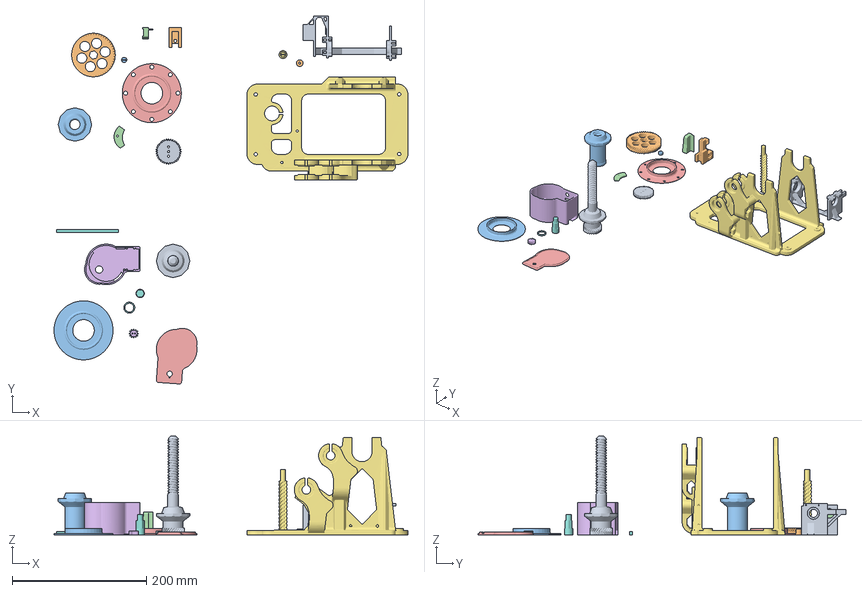
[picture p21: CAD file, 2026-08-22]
模型/配置/全部（单电机）.3mf
527.6 x 548.3 x 147.0 mm
Körper1.stl
实体16
Winder and Donor Right Hand Spool Axle Nut.stl
挂载电机部分.stl_6
线盘转动圈数被测器
组合体.stl
实体1 x 5
11.stl
实体6
Spooler%20Centering%20Disc%20for%20Bambu%20Lab%20Spools%2055%20mm.stl
电机压片.stl
挂载电机部分.stl_4
实体2
电机齿轮.stl

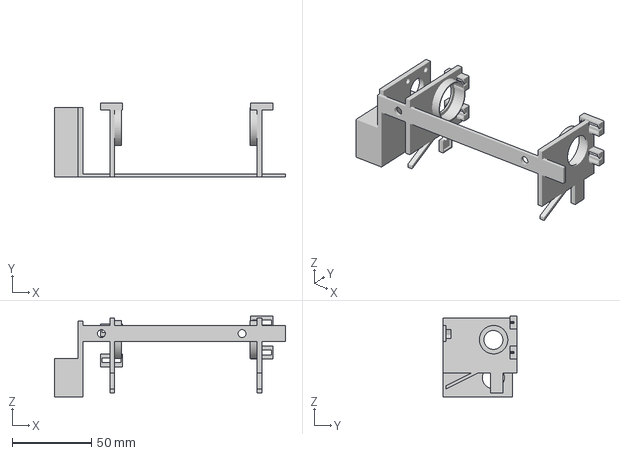
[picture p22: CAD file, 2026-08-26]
模型/核心.3mf
146.2 x 47.0 x 51.0 mm

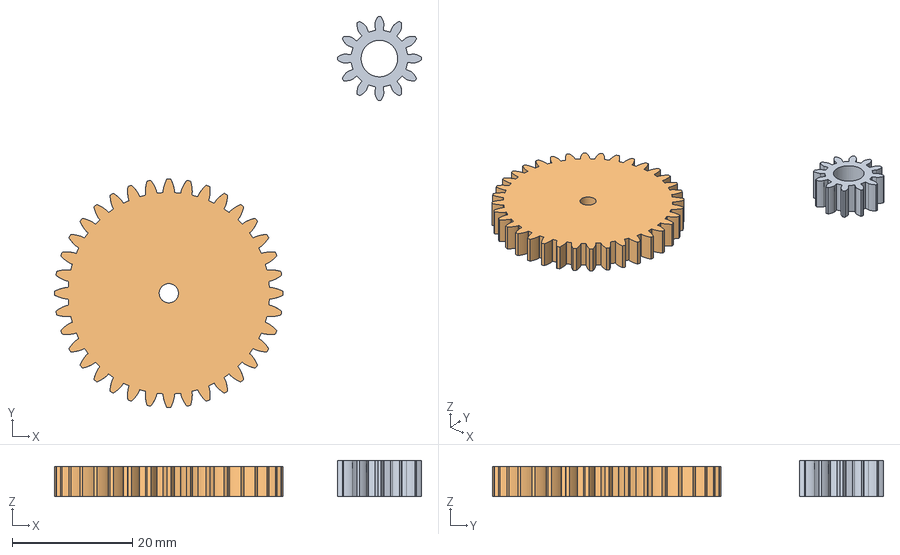
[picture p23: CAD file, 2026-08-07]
模型/源文件/齿轮.step
61.0 x 65.0 x 6.00 mm
InvoluteGear002
InvoluteGear003

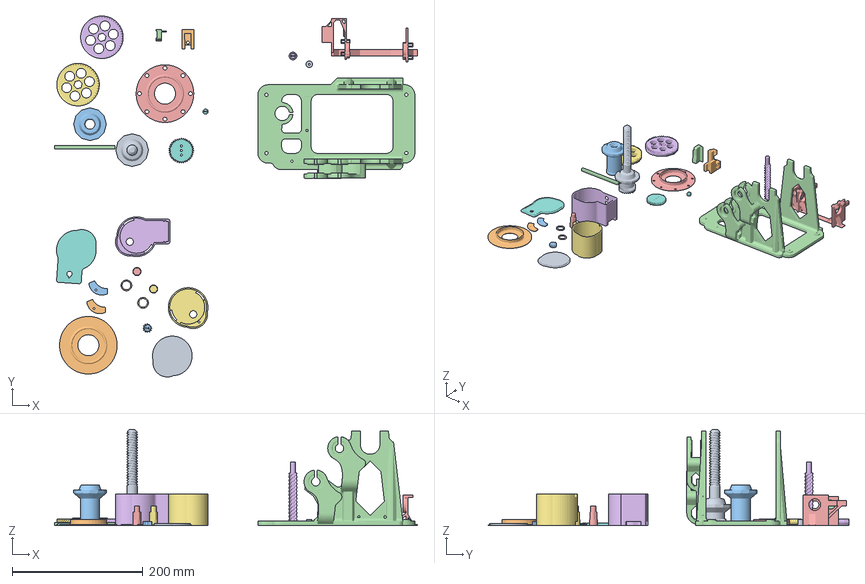
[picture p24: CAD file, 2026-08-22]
模型/配置/全部（双电机）.3mf
554.7 x 551.4 x 147.0 mm
Körper1.stl
实体16
Winder and Donor Right Hand Spool Axle Nut.stl
挂载电机部分.stl_6
线盘转动圈数被测器
实体1 x 5
11.stl x 2
实体6
Spooler%20Centering%20Disc%20for%20Bambu%20Lab%20Spools%2055%20mm.stl
组合体
双电机.stl
双电机A 盖子.stl
双电机盖子.stl
电机压片.stl.stl x 2
实体2
电机齿轮.stl x 2

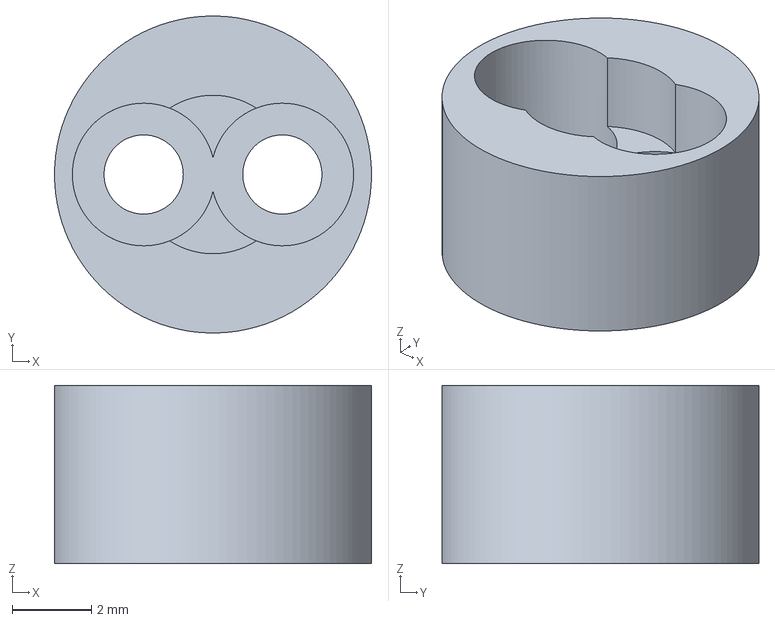
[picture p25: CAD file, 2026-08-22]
模型/as5600 磁铁放置.3mf
8.00 x 8.00 x 4.50 mm

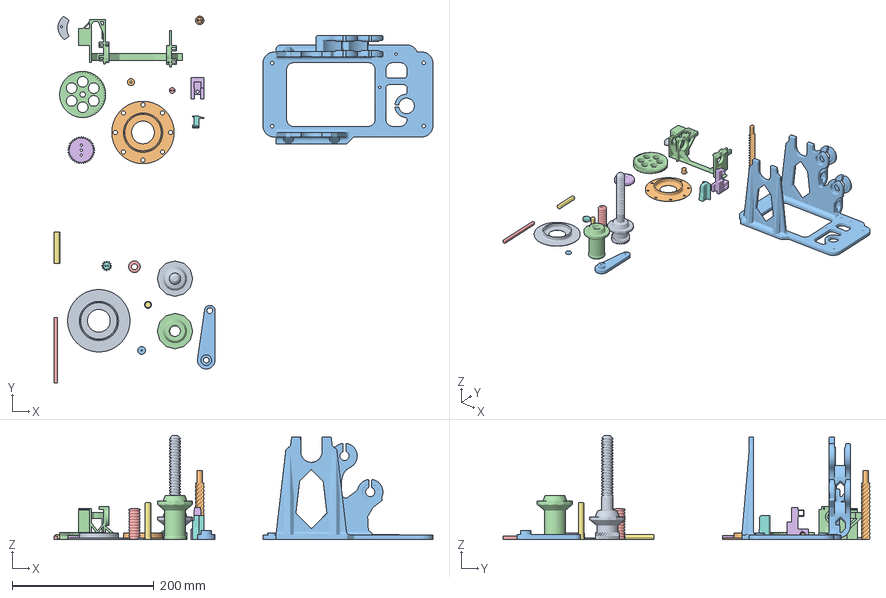
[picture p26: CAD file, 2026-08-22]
模型/配置/全部（手摇:电钻）.3mf
534.7 x 517.2 x 147.0 mm
Körper1.stl
实体1 x 5
Winder and Donor Right Hand Spool Axle Nut.stl
9.stl_2.stl
实体16
9.stl_4.stl
挂载电机部分.stl_6
Spooler%20Centering%20Disc%20for%20Bambu%20Lab%20Spools%2055%20mm.stl
线盘转动圈数被测器
9.stl_1_Boolean.stl
Gear 50 Upper.stl
Axis 47mm.stl.stl
电机压片.stl
实体6
9.stl_3.stl
实体2

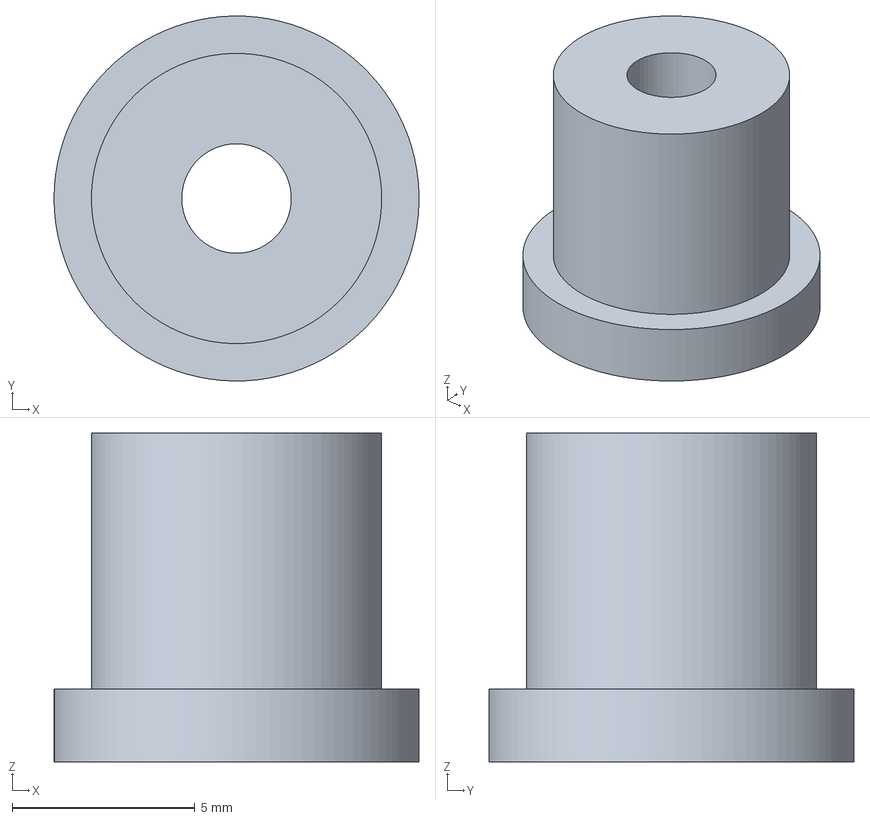
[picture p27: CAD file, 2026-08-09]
模型/丝杆固定.3mf
10.00 x 10.00 x 9.00 mm

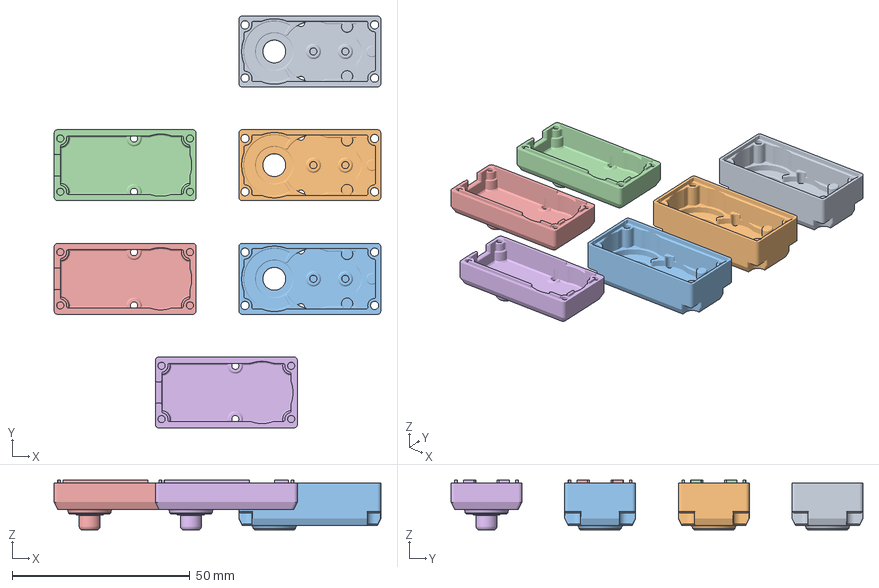
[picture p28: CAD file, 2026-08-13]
模型/配置/mg946 改双轴.3mf
92.0 x 116.0 x 14.0 mm
MG996R_adapter-A.STEP x 3
MG996R_adapter-B.STEP x 3

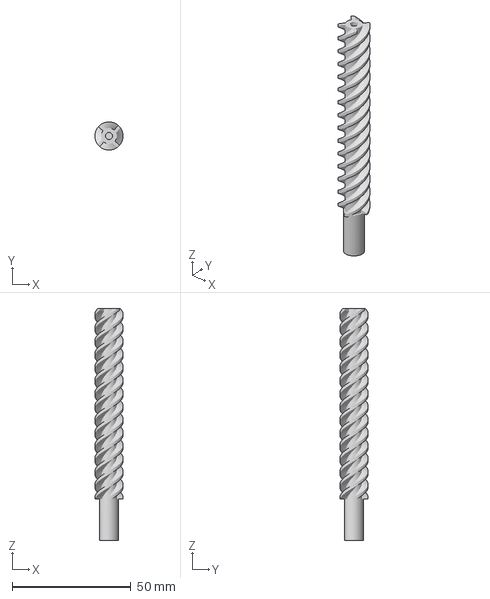
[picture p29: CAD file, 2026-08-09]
模型/丝杆.3mf
11.8 x 11.8 x 97.5 mm

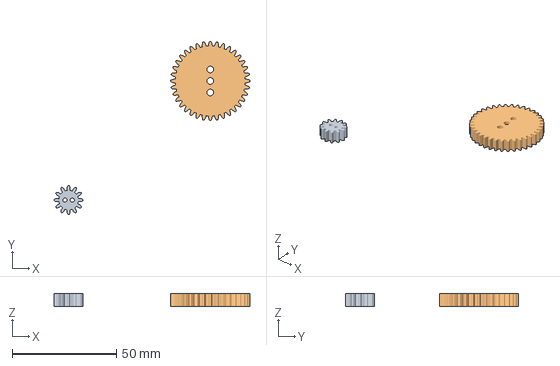
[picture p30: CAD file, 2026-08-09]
模型/从动小齿轮.3mf
93.8 x 83.0 x 6.00 mm
实体1 x 2

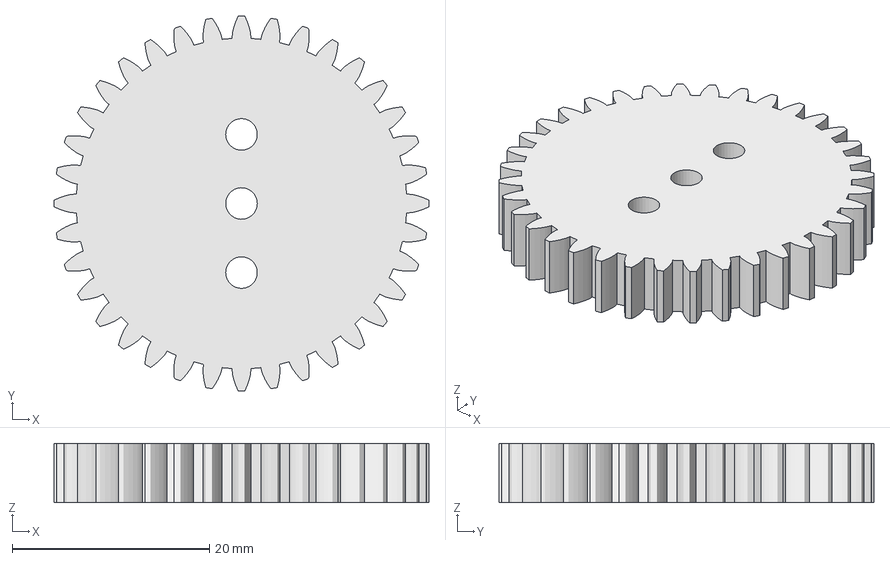
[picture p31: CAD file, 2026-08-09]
模型/主动大齿轮.3mf
38.0 x 38.0 x 6.00 mm

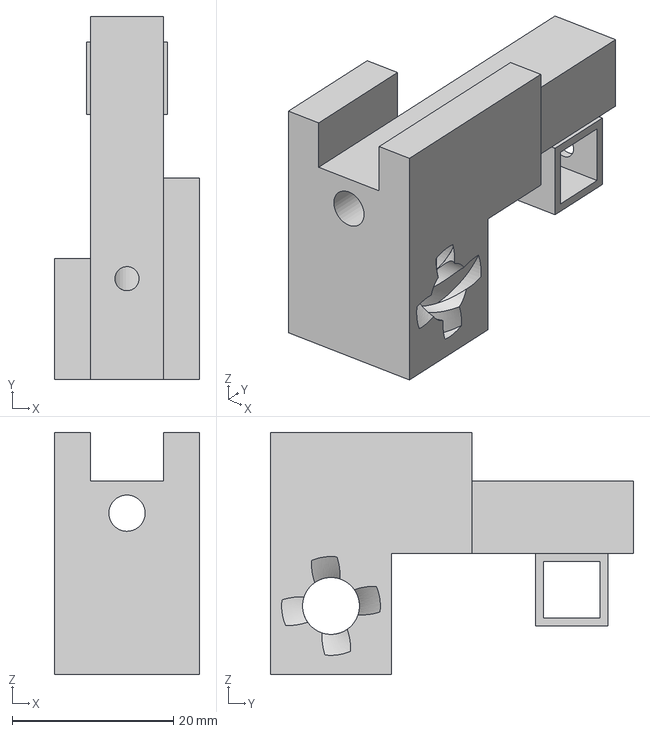
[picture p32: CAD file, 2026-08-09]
模型/导料嘴.3mf
18.0 x 45.0 x 30.0 mm

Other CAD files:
模型/平行于丝杆的定位小杆.3mf
模型/线盘转动圈数被测器.3mf
模型/源文件/608zz 轴承.f3d
模型/源文件/as5600 磁铁放置.f3d
模型/源文件/丝杆.f3d
模型/源文件/平行于丝杆的定位小杆.f3d
模型/源文件/线盘转动圈数被测器.f3d
模型/源文件/螺母.f3z
模型/源文件/螺母切割工具.f3d
模型/源文件/齿轮.FCStd
模型/源文件/齿轮.f3d

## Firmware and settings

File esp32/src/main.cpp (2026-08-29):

#include <Arduino.h>
#include "config.h"
#include "state.h"
#include "motor.h"
#include "servo.h"
#include "sensors.h"
#include "slip.h"
#include "storage.h"
#include "comms.h"
#include "protocol.h"
#include "winder.h"
#include "webui.h"
#include "led.h"
#include "license.h"
#include <WiFi.h>

void setup() {
    Serial.begin(115200);
    delay(1000);

    Serial.println("\n========================================");
    Serial.println("  耗材绕线器 ESP32 固件启动");
    Serial.println("========================================\n");

    // 1. 配置（纯 NVS，不碰外设）
    Serial.println("[Main] 1/5 加载配置");
    License::begin();
    g_storage.begin();
    g_storage.loadConfig(g_config);
    Serial.printf("[Main] 线径=%.2fmm 料盘宽=%.1fmm\n",
                  g_config.filamentDiameter, g_config.spoolWidth);

    // 2. 通信（最先初始化，此时系统干净，无外设干扰）
    Serial.println("[Main] 2/5 初始化 WiFi");
    g_comms.onMessage([](const String &msg) {
        g_protocol.handle(msg);
    });
    g_comms.begin();

    // 3. 硬件（即使 LEDC 出问题也不影响已建立的 WiFi）
    Serial.println("[Main] 3/5 初始化硬件");
    g_winder.begin();
    Serial.println("[Main] 硬件就绪");

    // 4. 状态灯
    Serial.println("[Main] 4/5 初始化状态灯");
    g_led.begin();

    // 5. Web 界面（WiFi 就绪后即可服务）
    Serial.println("[Main] 5/5 启动 Web 界面");
    g_webui.begin();

    License::onlineCheck();   // 联网心跳（阻塞可达数秒，必须在启动回原点之前完成，
                              // 否则 setup 卡在网络请求时小车已顶死限位而无法停车）
    g_winder.goHome();

    Serial.println("[Main] 初始化完成\n");
}

static uint32_t s_lastCheckMs = 0;
void loop() {
    // 在线心跳：联网前每 30 秒重试，连上后每小时一次
    // （开机时 WiFi 往往还没就绪，只查一次会漏掉封禁状态刷新）
    static uint32_t s_failCount = 0;
    // 常规 1 小时一次；联网失败时 30 秒重试直到成功（保证封禁状态最终同步）
    const uint32_t interval = s_failCount > 0 ? 30UL * 1000UL : 3600UL * 1000UL;
    if (millis() - s_lastCheckMs > interval) {
        s_lastCheckMs = millis();
        s_failCount = License::onlineCheck() ? 0 : s_failCount + 1;
    }
    g_winder.update();
    g_comms.update();
    g_webui.update();
    g_led.setState(g_state.state, false, g_state.wifiConnected);
    g_led.update();
}

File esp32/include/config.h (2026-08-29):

#ifndef CONFIG_H
#define CONFIG_H
//============================================================================
//  config.h — 耗材绕线器集中配置文件
//  所有可调参数的编译时默认值。运行时由 NVS 覆盖（APP 可改）。
//  对应文档「描述.md」第四节「配置文件规范」。
//============================================================================
#include <Arduino.h>

//============================================================================
//  4.2  引脚配置
//============================================================================
#define PIN_MOTOR_PWM         4       // 电机驱动（MOS 栅极 或 L298N IN1，由 motorDriver 配置决定）
#define PIN_SERVO_PWM         5       // 排线舵机 PWM
#define PIN_ENDSTOP           14       // Endstop 左限位信号（人视角左侧，绕线起始侧）
#define PIN_ENDSTOP_RIGHT     32       // Endstop 右限位信号（人视角右侧，原点侧）
#define PIN_HALL_SPOOL        27       // 霍尔 B — 料盘
#define PIN_ENC_SDA           21       // AS5600 编码器 SDA（可选，闭环排线用）
#define PIN_ENC_SCL           22       // AS5600 编码器 SCL

//============================================================================
//  4.3  传感器参数
//============================================================================
#define HALL_SPOOL_MAGNETS        8       // 料盘单圈磁铁数
#define HALL_DEBOUNCE_US          25000   // 霍尔去抖动 (us)。
                                          // 兼作脉冲合理性下限: 8磁铁时等效最大 ~300RPM，
                                          // 滤除电机PWM耦合到霍尔线的噪声脉冲（5ms 挡不住）
#define ENDSTOP_DEBOUNCE_US       20000   // Endstop 去抖动 (us)

//============================================================================
//  4.4  料盘参数 — 拓竹 1kg 默认
//============================================================================
#define SPOOL_OUTER_DIAMETER          200.0f  // 料盘外径 (mm)
#define SPOOL_WIDTH                   60.0f   // 料盘绕线区宽度 (mm，拓竹规格)
#define SPOOL_CORE_DIA_WITH_CARD      87.0f   // 有纸筒芯轴直径 (mm)
#define SPOOL_CORE_DIA_NO_CARD        81.5f   // 无纸筒芯轴直径 (mm)
#define FILAMENT_DIAMETER             1.75f   // 线径 (mm)

//============================================================================
//  4.5  运动参数
//============================================================================
#define TRAVERSE_LEFT_START       2.0f    // 绕线左起始位置 (mm)
#define TRAVERSE_RIGHT_END        62.0f   // 绕线右终止换向位置 (mm)，2~62 绕满 60mm 料盘
#define TRAVERSE_DIST_PER_REV     1.75f   // 料盘每转一圈排线移动距离 (mm)
#define LEAD_SCREW_PITCH          22.0f   // 丝杆导程 (mm/圈, T8 四头)
#define CAL_INTERVAL_ROUNDS       3       // 每 N 个来回校准一次
#define TRAVEL_RANGE_MM           62.0f   // 左右限位触发点之间的实际物理距离 (mm)

//============================================================================
//  4.6  舵机参数 — 鑫辉科技 18KG 数字舵机 (连续旋转)
//  PWM 范围 500-2500us, 50Hz
//============================================================================
#define SERVO_STOP_PULSE          1500    // 停止中位 (us)
#define SERVO_LEFT_PULSE          500     // 左行满速 (向 Endstop)
#define SERVO_RIGHT_PULSE         2500    // 右行满速 (远离 Endstop)
#define SERVO_HOME_PULSE          500     // 寻原点/校准满速左行 (us)
#define SERVO_PWM_FREQ            50      // PWM 频率 (Hz)
#define SERVO_PULSE_MIN           500     // 满速左行极限 (us)
#define SERVO_PULSE_MAX           2500    // 满速右行极限 (us)
#define SERVO_RES_BITS            14      // LEDC 分辨率位数
#define SERVO_MIN_FRAC            0.30f   // 开环兜底模式的固定步进偏移比例（绕线主路径为编码器闭环）

// 排线位置反馈: 0=开环估算 1=AS5600 磁编码器闭环（默认，实测重复性 ±0.1mm）
// 编码器直测丝杆 → 齿比 1.0，mm/圈 = 丝杆导程
#define TRAVERSE_ENCODER          1
#define ENC_GEAR_RATIO            1.0f
#define SERVO_TRAVERSE_SPEED_RIGHT  0.0f  // 右行线速度 (mm/s, 0=未标定)
#define SERVO_TRAVERSE_SPEED_LEFT   0.0f  // 左行线速度 (mm/s, 0=未标定)

//============================================================================
//  4.7  电机参数
//============================================================================
#define DRIVE_MODE               0       // 驱动模式: 0=电动(电机驱动) 1=手动(手摇驱动)
#define MOTOR_PWM_FREQ            20000   // PWM 频率 (Hz)。
                                          // 用 20kHz 而非 1kHz: GPIO4 与舵机信号线相邻，
                                          // 低频 PWM 会耦合进舵机信号导致排线缓慢漂移
#define MOTOR_RES_BITS            10      // LEDC 分辨率位数 (0-1023)
#define MOTOR_MIN_SPEED           20      // 最低稳定转速 (%)
#define MOTOR_DEFAULT_SPEED       100     // 默认运行速度 (%)
#define MOTOR_MAX_SPEED           100     // 最大转速 (%)
#define MOTOR_SOFT_START_MS       1000    // 软启动时间 (ms)

// 缠料检测（电动模式）: 电机运转但霍尔测得料盘 RPM 低于阈值并持续该时长 → 报错
#define JAM_DETECT_MS             4000    // 判定时长 (ms，> 软启动时间)
#define JAM_MIN_RPM               1.0f    // 料盘视为停转的 RPM 阈值
#define JAM_MIN_MOTOR_PCT         10.0f   // 电机速度高于此值才参与判定

// 停转校准（手动模式）: 手摇停转持续该时长且来回数已达标 → 触发周期校准
#define MANUAL_STOP_CALIB_MS      2000    // 停转持续时间 (ms)
#define MANUAL_MIN_RPM            0.5f    // 视为停转的 RPM 阈值
#define SPOOL_STOP_MS             1000    // 超过该时长无霍尔脉冲 → 判定料盘停转


//============================================================================
//  4.9  通信参数
//============================================================================
#define WIFI_TCP_PORT             8080
#define STATUS_REPORT_INTERVAL_MS 500
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

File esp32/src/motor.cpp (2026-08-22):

#include "motor.h"

Motor g_motor;

void Motor::begin(uint8_t pin, uint16_t freq, uint8_t resBits) {
    if (_initialized) return;
    _pin     = pin;
    _freq    = freq;
    _resBits = resBits;
    _maxDuty = (1 << resBits) - 1;

    uint32_t actualFreq = ledcSetup(_channel, _freq, _resBits);
    if (actualFreq == 0) {
        Serial.printf("[Motor] LEDC 初始化失败! channel=%d freq=%d bits=%d\n",
                      _channel, _freq, _resBits);
        return;
    }
    Serial.printf("[Motor] LEDC OK: ch=%d freq=%d bits=%d actual=%d\n",
                  _channel, _freq, _resBits, actualFreq);

    ledcAttachPin(_pin, _channel);
    ledcWrite(_channel, 0);
    _currentSpeed = 0;
    _targetSpeed  = 0;
    _initialized  = true;
}

void Motor::reattach(uint8_t pin) {
    if (_pin != 0) ledcDetachPin(_pin);
    _pin = pin;
    ledcAttachPin(_pin, _channel);
    ledcWrite(_channel, 0);
}

void Motor::setDriver(uint8_t d) {
    if (!_initialized || d == _driver) { _driver = d; return; }
    _driver = d;
    if (d == 1) {
        // L298N 开关模式: 放弃 PWM，引脚改普通输出。
        // ENA 插跳线帽保持全速使能，本引脚接 IN1（IN2 接 GND），
        // 高=转 低=停，方向由接线决定。
        ledcDetachPin(_pin);
        ledcWrite(_channel, 0);
        pinMode(_pin, OUTPUT);
        digitalWrite(_pin, LOW);
        _l298On = false;
        Serial.println("[Motor] 驱动模式: L298N 开关（不调速）");
    } else {
        pinMode(_pin, OUTPUT);
        digitalWrite(_pin, LOW);
        ledcAttachPin(_pin, _channel);
        ledcWrite(_channel, 0);
        _currentSpeed = 0;
        _targetSpeed  = 0;
        Serial.println("[Motor] 驱动模式: MOS PWM 调速");
    }
}

void Motor::setSpeedPct(float pct) {
    if (pct < 0) pct = 0;
    if (pct > 100) pct = 100;
    _targetSpeed = pct;
}

void Motor::update() {
    if (!_initialized) return;
    if (_driver == 1) {
        // L298N: 无调速，目标 >0 即通电，=0 即断电。保留软启动斜坡仅作
        // 状态显示（缠料检测读 getCurrentSpeedPct）
        bool on = (_targetSpeed > 0.5f);
        if (on != _l298On) {
            _l298On = on;
            digitalWrite(_pin, on ? HIGH : LOW);
        }
        _currentSpeed = on ? 100.0f : 0.0f;
        return;
    }
    if (_currentSpeed == _targetSpeed) {
        _lastUpdateMs = millis();
        return;
    }
    uint32_t now   = millis();
    uint32_t dt    = now - _lastUpdateMs;
    _lastUpdateMs  = now;
    if (dt == 0) return;
    float step = (100.0f * dt) / _softStartMs;
    if (_targetSpeed > _currentSpeed) {
        _currentSpeed += step;
        if (_currentSpeed > _targetSpeed) _currentSpeed = _targetSpeed;
    } else {
        _currentSpeed -= step * 2;
        if (_currentSpeed < _targetSpeed) _currentSpeed = _targetSpeed;
    }
    uint32_t duty = (uint32_t)(_currentSpeed / 100.0f * _maxDuty);
    ledcWrite(_channel, duty);
}

void Motor::stop() {
    _targetSpeed  = 0;
    _currentSpeed = 0;
    if (!_initialized) return;
    if (_driver == 1) {
        _l298On = false;
        digitalWrite(_pin, LOW);
    } else {
        ledcWrite(_channel, 0);
    }
}

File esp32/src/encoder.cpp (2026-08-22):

#include "encoder.h"
#include <Wire.h>
#include "freertos/FreeRTOS.h"
#include "freertos/task.h"

TraverseEncoder g_encoder;

static const uint8_t AS5600_ADDR = 0x36;

bool TraverseEncoder::begin(uint8_t sda, uint8_t scl) {
    if (_begun) return _ok;
    _sda = sda; _scl = scl;
    Wire.begin(sda, scl);
    // 100kHz: 现场实测 400kHz 在舵机/电机 EMI 下会总线锁死（连续 NACK +
    // 垃圾数据），慢边沿对噪声容忍度高得多。排线场景 1kHz 轮询绰绰有余
    Wire.setClock(100000);
    // 试读一次验证在位
    uint16_t raw = readRawAngle();
    _ok = (raw != 0xFFFF);
    _lastRaw = (raw == 0xFFFF) ? 0 : raw;
    _begun = true;
    Serial.printf("[Encoder] AS5600 初始化: %s (raw=%u)\n",
                  _ok ? "在位" : "无响应", _lastRaw);

    // 独立 1kHz 轮询任务: 跑在 core 1（core 0 是 WiFi 协议栈，事件忙起来
    // 会把轮询饿出 20ms+ 的洞，跨圈解包就错了）
    xTaskCreatePinnedToCore(pollTask, "enc_poll", 2048, this, 3, nullptr, 1);
    return _ok;
}

// I2C 总线恢复: 从机被 EMI 打挂卡死 SDA 后，唯一办法是发 9+ 个 SCL 脉冲
// 让从机吐出残余位，然后重新初始化总线
static void busRecover(uint8_t sda, uint8_t scl) {
    Wire.end();
    pinMode(scl, OUTPUT_OPEN_DRAIN);
    pinMode(sda, INPUT_PULLUP);
    for (int i = 0; i < 16; i++) {
        digitalWrite(scl, LOW);
        delayMicroseconds(5);
        digitalWrite(scl, HIGH);
        delayMicroseconds(5);
    }
    Wire.begin(sda, scl);
    Wire.setClock(100000);
}

uint16_t TraverseEncoder::readRawAngle() {
    Wire.beginTransmission(AS5600_ADDR);
    Wire.write(0x0C);              // 角度高字节寄存器
    if (Wire.endTransmission(false) != 0) return 0xFFFF;
    if (Wire.requestFrom((int)AS5600_ADDR, 2) != 2) return 0xFFFF;
    uint16_t h = Wire.read();
    uint16_t l = Wire.read();
    return ((h & 0x0F) << 8) | l;  // 12bit
}

void TraverseEncoder::pollTask(void *arg) {
    TraverseEncoder *self = static_cast<TraverseEncoder *>(arg);
    uint32_t lastPollMs = 0;
    uint32_t prevPollMs = 0;
    uint16_t errStreak = 0;
    while (true) {
        uint32_t now = millis();
        if (lastPollMs != 0) {
            uint32_t iv = now - lastPollMs;
            if (iv > self->_maxPollMs) self->_maxPollMs = iv;
        }
        prevPollMs = lastPollMs;
        lastPollMs = now;

        // 连续失败 → 总线锁死，脉冲恢复后重试
        if (errStreak >= 20) {
            busRecover(self->_sda, self->_scl);
            errStreak = 0;
            vTaskDelay(pdMS_TO_TICKS(50));
            continue;
        }

        uint16_t raw = self->readRawAngle();
        if (raw == 0xFFFF) {
            self->_ok = false;
            errStreak++;
        } else {
            self->_ok = true;
            errStreak = 0;
            int32_t delta = (int32_t)raw - (int32_t)self->_lastRaw;
            if (delta > 2048)  { delta -= 4096; self->_unwrapCorr++; }
            if (delta < -2048) { delta += 4096; self->_unwrapCorr++; }
            // 垃圾读数防护: 正常轮询间隔(≤5ms)下单拍增量不可能超过半圈的 1/4，
            // 超过必是 EMI 破坏的数据——丢弃，不累计（累计了就是 ±22mm 跳变）
            uint32_t gap = now - prevPollMs;
            if (abs(delta) > 512 && gap <= 5) {
                self->_lastRaw = raw;   // 角度本身可信，仅不累计本拍增量
            } else {
                self->_totalCounts += delta;
                self->_lastRaw = raw;
            }

            // 速度测量: ≥20ms 窗口 → EMA
            self->_spdAccCounts += delta;
            uint32_t win = now - self->_spdWinMs;
            if (win >= 20) {
                float v = (self->_spdAccCounts / 4096.0f) * self->getMmPerRev()
                        * 1000.0f / (float)win * self->_sign;
                self->_speedMmPerS = self->_speedMmPerS * 0.6f + v * 0.4f;
                self->_spdAccCounts = 0;
                self->_spdWinMs = now;
            }
        }
        vTaskDelay(pdMS_TO_TICKS(1));   // 1kHz
    }
}

float TraverseEncoder::posMm() const {
    return (float)_totalCounts * _mmPerCount * _sign;
}

float TraverseEncoder::getRevs() const {
    return ((float)_totalCounts / 4096.0f) * _sign;
}

float TraverseEncoder::getSpeedMmPerS() const {
    return _speedMmPerS;
}

void TraverseEncoder::setPosMm(float pos) {
    _totalCounts = (int32_t)(pos / (_mmPerCount * _sign));
}

void TraverseEncoder::setMmPerRev(float mmPerRev) {
    if (mmPerRev < 0.1f || mmPerRev > 500.0f) return;
    float mm = posMm();            // 保持当前位置不变
    _mmPerCount = mmPerRev / 4096.0f;
    _totalCounts = (int32_t)(mm / (_mmPerCount * _sign));
}

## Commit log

2026-08-02 第一个不稳定版本，考虑不使用 arduino esp
2026-08-02 项目改用 esp32，发现原本的 dhcp 问题为 mac 连接独有问题，使用手机连接正常，暂未修复
    [comms.cpp, config.h, main.cpp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]
2026-08-02 更新文档，优化配网
2026-08-02 局域网设备发现（似乎用不了），优化配网
2026-08-02 优化配网逻辑，允许直接输入 ip 连接
2026-08-02 忘了优化了什么，反正优化了
2026-08-02 优化 app 的速度滑杆
2026-08-07 完成内网搜索设备
    [丝杆.3mf, 丝杆与导料嘴.3mf, 主动大齿轮.3mf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]
2026-08-08 （备注：上一个版本还增加了电机速度的校准，把霍尔传感器改成了 1 个）
    [左右横移导料嘴.3mf]
2026-08-09 更新默认配置，丝杆生成脚本，并更改状态灯
2026-08-09 更改状态灯，默认配置，还有丝杆生成脚本
2026-08-09 整理模型
    [BOM.csv, 丝杆.3mf, 丝杆与导料嘴.3mf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]
2026-08-10 bom，修复舵机运动的问题（没完全修复）
    [BOM.csv]
2026-08-10 更新 readme
2026-08-10 更新模型
    [主体.3mf, 全部.3mf, 核心.3mf]
2026-08-10 更新 bom，效果图，readme
    [BOM.csv]
2026-08-10 删除过时文件，更新打印配置
    [全部.3mf]
2026-08-12 更新 bom 和模型，增加收款码
    [BOM（单电机）.csv, BOM（双电机）.csv, BOM（手摇:电钻).csv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]
2026-08-12 上传 3d 文件
    [608zz 轴承.f3d, 丝杆.f3d, 平行于丝杆的定位小杆.f3d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]
2026-08-13 更改首选舵机，BOM，改 3d 原文件的螺母尺寸
    [BOM（单电机）.csv, BOM（双电机）.csv, BOM（手摇:电钻).csv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]
2026-08-13 删蓝牙，优化阅读体验，平滑舵机运动
    [BOM（单电机）.csv, BOM（双电机）.csv, BOM（手摇:电钻).csv]
2026-08-14 更新配置文件
    [全部（单电机）.3mf, 全部（双电机）.3mf, 全部（手摇:电钻）.3mf]
2026-08-14 添加 Gradle wrapper 文件（构建必需）
    gradlew / gradlew.bat / gradle-wrapper.jar 被 Flutter 默认 .gitignore 排除，
    但 clone 后缺少这些文件会导致 flutter build apk 失败
2026-08-14 渲染 readme
2026-08-16 一次改了很多，不知道能不能用，增加了两种模式，电动和手动，增加了缠料检测的实现，替换了 mos 管，换成IRLB8721（搭配150Ω/10kΩ 电阻和 1N5822），在霍尔测试里面增加了转速的统计
    [BOM（单电机）.csv, BOM（双电机）.csv, BOM（手摇:电钻).csv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]
2026-08-20 实现编码器的闭环控制，但还没测试
    [as5600 磁铁放置.3mf, as5600 磁铁放置.f3d, as5600.step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]
2026-08-20 删除 bom 耗材费
    [BOM（单电机）.csv, BOM（双电机）.csv, BOM（手摇:电钻).csv]
2026-08-20 改 bom，做 web ui，应对 ios 没有 app，让 esp32 和设备在同一个局域网时可以直接设备访问 iwinder.local 连接（mdns）
    [BOM（单电机）.csv, BOM（双电机）.csv, BOM（手摇:电钻).csv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]
2026-08-22 大量更改，主要重构了项目，使清晰，但是绕线似乎还是不可用
    [as5600 磁铁放置.3mf, as5600 磁铁放置.f3d]
2026-08-22 基本能用了
2026-08-22 l298n 替代，基本完成，但是舵机在正常绕线时左右跳动
    [核心.3mf]
2026-08-22 更新 readme 和一些过时的东西
2026-08-22 重构: 核心算法闭源化，分层许可证，加入设备授权申请流程
2026-08-23 Web 界面: 补 WiFi 配网页 + 电机驱动电路(L298N 开关)选项
    热点模式(192.168.4.1)此前没有配网入口，App 不在身边时无法配网；
    新增 SSID/密码表单直接下发 set_wifi。参数页增加电机驱动电路下拉
    (MOS PWM 调速 / L298N 开关不调速)。gitignore 排除本地数据文件。
2026-08-23 Web 界面: 绕线范围右基准模型（左起始 = 右终止 − 料盘宽度）
    与 App 同步: 左起始只读自动推导，'左起始手动指定'勾选覆盖特殊
    安装；改料盘宽度即换盘，不再手填三个可能打架的参数。
2026-08-23 发布 v0.2.0: 编译好的固件二进制与 APP 安装包
    - firmware/: iwinder-v0.2.0-full.bin（合并镜像，浏览器/命令行一步烧录）
    + 仅应用固件 + 烧录说明（web.esptool.fun 一键烧录）
    - apk/: winder-app-v0.2.0.apk（含设备授权页、绕线范围右基准联动）
    - README: 下载指引指向仓库内目录；绕线范围说明更新为右基准模型；
    项目结构补充 firmware/ apk/；版本徽章 v0.2
2026-08-23 烧录: 改用 esptool.spacehuhn.com 网页烧录器（四槽位方案）
    网页烧录器为固定四槽位布局(0x1000/0x8000/0xE000/0x10000)，
    不能用合并镜像的单槽方案。补齐 bootloader/partitions/boot_app0
    三个分文件，firmware/README.md 提供槽位对照表；另附'仅升级
    0x10000'的增量烧录说明。主 README 同步更新烧录步骤。
2026-08-23 App 源码同步至 v0.2.0（与发布 APK 一致）
    从开发仓库同步三个文件的差异:
    - 设备授权: 查询/激活 UI（设置页授权卡片）
    - 绕线范围右基准模型: 左起始自动推导 + 手动覆盖开关 + 一致性校验
2026-08-23 烧录说明简化: 网页烧录器改为单文件方案
    槽位地址可编辑，合并镜像填 0x0 一个槽即可，不再需要四文件分填。
    四文件方式折叠为备选。
2026-08-23 固件 v0.2.1
    - 缠料检测走暂停流程（清理后点恢复继续，不再要求重新寻原点）
    - 恢复运行后电机正确重启（暂停/恢复闭环修复）
    - AP 模式下 UDP 发现套接字初始化（修 parsePacket 狂报错，
    连热点的手机也能搜到设备）
2026-08-23 App 默认行程参数同步: 右终止/限位间距 62mm
2026-08-23 固件 v0.2.2: 默认行程参数 62/62/2（绕满 60mm 料盘）
    限位间距 62mm，右终止 62mm，左起始 2mm → 绕线宽度 60mm。
    含 v0.2.1 全部修复（缠料暂停流程、恢复电机重启、AP UDP 修复）。
2026-08-23 README 更新至 v0.2.2 稳定版
    - 状态徽章 beta → stable（第一个完整版本）
    - 行程参数: 限位间距/右终止 62mm（绕满 60mm 料盘）
    - 缠料保护描述: 报错 → 自动暂停 + 恢复继续
    - 所有默认值与 v0.2.2 固件一致
2026-08-23 文档: 申请授权补充一键申请与授权网站入口
2026-08-23 gitignore release 产物目录
2026-08-25 更新模型文件
    [核心.3mf]
2026-08-25 固件: 仓库内提供 v0.2.5 固件与APP（历史版本见 Releases）
2026-08-25 文档: APP 下载指向 firmware 目录
2026-08-26 增加安装说明
    [核心.3mf]
2026-08-29 v0.2.8: 修复启动顶限位 + 文档与 APP 同步
    - 固件/APP 更新至 v0.2.8（详见 Release 说明）
    - README: 版本号 v0.2.8、烧录文件名、结构树修正、安装说明链接、限位接反排查提示
    - APP 源码同步: 在线授权申请/OTA 卡片、限位引脚默认值 左=14 右=32
    - 新增安装说明文档；更新核心件模型
    [主体.3mf]
2026-08-29 OTA 检查按钮加载反馈（APP/WebUI 源码同步 v0.2.9）
2026-08-29 固件: v0.2.9 产物更新
2026-08-29 授权按钮忙态与 HTTP 超时修复（源码同步）
2026-08-29 固件: v0.2.10 产物更新
    [主体.3mf]

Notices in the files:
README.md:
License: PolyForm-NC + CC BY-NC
